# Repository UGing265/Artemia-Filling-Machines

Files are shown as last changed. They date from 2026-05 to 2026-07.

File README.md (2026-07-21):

# Máy Chiết Artemia

Máy chiết chiết tự động cho artemia (tôm muối) với kiểm soát thể tích chính xác và giám sát thời gian thực.

## Vấn Đề

Chiết chiết ống tube thủ công cho artemia tốn thời gian và không nhất quán. Mỗi ống cần liều lượng chính xác 5ml với xác nhận trực quan, và việc theo dõi số lượng ống trong quá trình xử lý là rất quan trọng để kiểm soát chất lượng.

## Giải Pháp

Hệ thống chiết tự động dựa trên Arduino:
- Chiết ống với thể tích tự động dựa trên cài đặt thời gian
- Đếm số ống đã chiết bằng cảm biến quang điện
- Hiển thị tốc độ, thời gian bơm và số lượng ống thời gian thực trên LCD
- Điều chỉnh tốc độ bơm và thời gian chiết trực tiếp bằng 2 biến trở độc lập
- Hỗ trợ hủy quá trình khẩn cấp (Abort) bằng nút bấm cứng

## Linh Kiện

| Linh Kiện | Công Dụng |
|---|---|
| Arduino CNC Shield V3.00 | Board điều khiển chính |
| L298N DC Motor Driver | Điều khiển tốc độ/chiều motor bơm |
| Nema 17 Stepper Motor | Truyền động cơ cấu xoay |
| LCD 16x4 I2C (PCF8574) | Hiển thị trạng thái và thông số |
| Cảm Biến Quang (E3F-DS30C4) | Phát hiện vị trí ống để đếm và kích hoạt bơm |
| Công Tắc Hành Trình (JL012-13) | Nút hủy quá trình (Abort) / Homing |
| 2 x Biến Trở 10K | Điều chỉnh tốc độ bơm và thời gian bơm |
| Bơm Peristaltic 5V | Chiết dung dịch artemia |

## Máy Trạng Thái

```text
ROTATING (Xoay mâm) → SENSOR_CHECK (Kiểm tra ống)
      ├─ [Có ống] → PUMP_WAIT (Đợi ổn định 1s) → PUMP_FILL (Bơm dung dịch) → PUMP_DONE (Đợi 3s) → ROTATING
      └─ [Không ống] → NO_TUBE_WAIT (Đợi 5s) → ROTATING

* Nút Abort: Hủy quá trình đang chạy bất kỳ lúc nào và đưa hệ thống về trạng thái ban đầu.
* Bơm sẽ tự dừng nếu mất ống (rớt ống) trong quá trình bơm.
```

## Điều Chỉnh Bơm Trực Tiếp

Hệ thống cho phép điều chỉnh trực tiếp các thông số bơm thông qua 2 núm vặn:
1. **Biến trở tốc độ (Chân A1):** Điều chỉnh tốc độ quay của động cơ bơm (PWM: 0 - 255).
2. **Biến trở thời gian (Chân A2):** Điều chỉnh thời gian bơm cho mỗi ống (từ 2.0 giây đến 20.0 giây).
Mọi thay đổi đều được cập nhật thời gian thực trên màn hình LCD.

## Demo

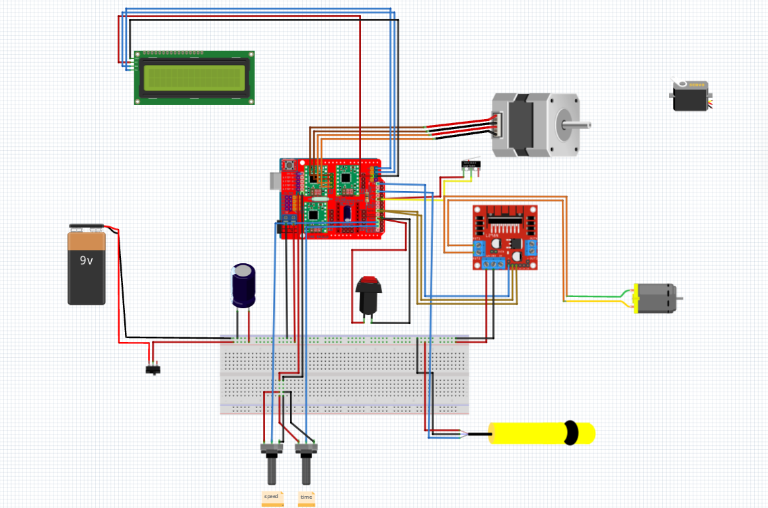
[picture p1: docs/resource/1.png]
Demo Máy Chiết


Video Demo (https://youtu.be/GX13D0-sERE)

## Nhóm

- **kiến trúc sư**: ZT
- **kĩ sư**: DevShiroru

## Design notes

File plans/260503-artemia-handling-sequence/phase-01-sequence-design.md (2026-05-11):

# Phase 1: Artemia Handling Sequence Design

## Context Links
- Main code: `ArtemiaCode/ArtemiaCode.ino`
- Plan: `plans/260503-artemia-handling-sequence/plan.md`

## Overview
- Priority: P1 (High)
- Status: Completed
- Brief description: Design sensor-triggered pump sequence replacing current hardcoded rotation+pump cycle

## Current Behavior (loop())

Current code in `loop()`:
1. Run stepper 1 revolution (stepsPerRev steps)
2. delay(1000) - rest 1 second
3. runPumpCycle() - pump 2 seconds OR until 5ml
4. displayUpdate()

This is HARDCODED - no sensor awareness.

## Required Behavior

```
loop()
├── Check abort button (existing)
├── Handle calibration states (existing)
└── IDLE state → NEW SEQUENCE:

    Step A: Rotate 1 revolution
    │
    Step B: Check sensor immediately after rotation
    │       └── If sensor HIGH (tube detected):
    │               ├── Wait 3s
    │               ├── Pump ON → auto-stop at 5ml (timeout 5s)
    │               ├── Pump OFF
    │               ├── tubeCount++
    │               ├── Wait 5s
    │               └── → back to Step A
    │       └── If sensor LOW (no tube):
    │               ├── Wait 10s (user places tube)
    │               └── → back to Step A
    │
```

## Key Design Decisions

### 1. Sensor Detection Timing
- Sensor is checked AFTER rotation completes
- If tube detected → 3s delay → pump (5ml over ~5s)
- If no tube → 10s wait → next rotation (giving user time to place tube)

### 2. 3s Delay Before Pumping
- Purpose: Let tube settle into position
- Prevents premature pumping

### 3. Pump Auto-Stop
- Stop at TARGET_VOLUME (5ml) with ~5s timeout
- Use flowRateCalibrated for volume estimation

### 4. Post-Pump Sequence
- Increment tubeCount
- Wait 5s (tube settling)
- Continue to next rotation

### 5. No-Tube Timeout
- After full rotation with no tube detected
- Wait 10s (polling sensor during this time)
- If tube placed within 10s → trigger pump sequence
- If timeout → continue rotation anyway

## Sequence State Machine

```cpp
enum HandleState {
  ROTATING,        // Stepper rotating 1 revolution
  SENSOR_CHECK,   // After rotation, check sensor
  PUMP_WAIT,      // Waiting 1s before pump
  PUMPING,        // Pump running, auto-stop
  PUMP_DONE,      // Pump stopped, wait 2s
  NO_TUBE_WAIT    // No tube detected, wait 10s
};
```

## Edge Cases

| Case | Handling |
|---|---|
| Tube removed during pumping | Continue until 5ml |
| Sensor flickers | Debounce 50ms (existing DEBOUNCE_SENSOR) |
| Button pressed during sequence | abortAll() immediately |
| Power loss during pump | pumpRunning flag reset on startup |

## LCD Display Updates

During sequence:
```
Line 0: "MAY CHIET ARTERMIA"
Line 1: "Speed:XXX"
Line 2: "Tubes:X |....|"
Line 3: "Time:Xs"
```

Where:
- Speed: current pump PWM (0-255)
- Tubes: count of filled tubes
- Time: processing time (adjustable 2s-20s via potentiometer)
- Bar: filled `|` = tube detected, empty `-` = no tube

Where YYY = ROTATE | WAIT1S | PUMPING | WAIT2S | NO_TUBE | DONE

## Related Code Changes

Files to modify: `ArtemiaCode/ArtemiaCode.ino`
- Add `HandleState` enum
- Add state variable `HandleState handleState = ROTATING`
- Add state timer `unsigned long stateStartTime = 0`
- Add processing time variable `int processingTimeS = 5` (default, adjustable 2-20s)
- Replace IDLE loop content with state machine
- Rewrite `displayUpdate()` to new LCD layout (MAY CHIET ARTERMIA title)
- Add sensor status to LCD (HI/LO)
- Potentiometer A1 adjusts processing time (2s-20s mapped from 0-1023)

## Implementation Steps

1. Add `HandleState` enum after existing enums
2. Add state variables: `handleState`, `stateStartTime`
3. Rewrite IDLE loop section as state machine
4. Add `checkOverflow()` helper in pump cycle
5. Add LCD state display in `displayUpdate()`
6. Test sequence with physical hardware

## Todo List
- [ ] Add HandleState enum
- [ ] Add state variables
- [ ] Implement state machine in loop()
- [ ] Update displayUpdate() with state info
- [ ] Compile and verify

## Success Criteria
- [ ] Sensor HIGH → 3s delay → pump fills 5ml → stops
- [ ] After pump: tubeCount++, wait 5s, rotate
- [ ] No tube after rotation → wait 10s, rotate (no pump)
- [ ] Processing time adjustable via pot (2s-20s)
- [ ] LCD shows: MAY CHIET ARTERMIA, Speed, Tubes, Time, Sensor status
- [ ] Abort button works during any state

## Risk Assessment
- Risk: State machine complexity
- Mitigation: Keep states simple, each does one thing
- Risk: Timing sensitive (1s, 2s, 10s)
- Mitigation: Use millis() for accurate timing

## Security Considerations
- User can always abort via button
- Overflow protection prevents mess
- No network/internet access

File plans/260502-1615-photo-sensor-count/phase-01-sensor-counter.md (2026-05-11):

---
title: "Phase 1: Photoelectric Sensor + Tube Counter"
description: "Implement photoelectric sensor detection and tube counting with reset button"
status: completed
owner: claude
priority: P2
created: 2026-05-02
---

## Context Links

- Parent: [plan.md](../plan.md)
- Code: `ArtemiaCode/ArtemiaCode.ino`

## Overview

Add photoelectric sensor to count tubes and push button to reset counter.

### Pin Assignment

| Component | Pin | Mode |
|---|-----|---|
| Photoelectric sensor | D10 (Y+) | INPUT_PULLUP (NC = no object, LOW = object detected) |
| Reset button | A0 (Abort) | INPUT_PULLUP (NC = not pressed, LOW = pressed) |

### Debounce

- Sensor: 50ms debounce to avoid double-counting
- Button: 100ms debounce for mechanical switch

## Requirements

1. Photoelectric sensor on D7 - detect falling edge (HIGH→LOW transition means object detected)
2. Tube counter variable `tubeCount` starts at 0
3. Each detection: tubeCount++
4. Push button on D6 - when pressed, set tubeCount = 0
5. No LCD changes in this phase

## Implementation Steps

1. Define pin constants: `sensorPin = 7`, `resetBtnPin = 6`
2. Add `tubeCount` global variable (int)
3. Add `lastSensorTrigger = 0` for debounce timing
4. In setup(): `pinMode(sensorPin, INPUT_PULLUP)`, `pinMode(resetBtnPin, INPUT_PULLUP)`
5. In loop(): implement detection logic:
   - Read sensor: if LOW and (now - lastSensorTrigger) > 50ms → count++
   - Read button: if LOW → reset tubeCount to 0
   - Update lastSensorTrigger on count

## Code Snippet

```cpp
const int sensorPin = 10;   // Y+ on CNC shield (D10)
const int resetBtnPin = A0; // Abort signal (A0)

int tubeCount = 0;
unsigned long lastSensorTrigger = 0;
const int DEBOUNCE_SENSOR = 50;
const int DEBOUNCE_BUTTON = 100;

void setup() {
  pinMode(sensorPin, INPUT_PULLUP);
  pinMode(resetBtnPin, INPUT_PULLUP);
}

void loop() {
  // Sensor detection (NC = HIGH, detected = LOW)
  if (digitalRead(sensorPin) == LOW &&
      millis() - lastSensorTrigger > DEBOUNCE_SENSOR) {
    tubeCount++;
    lastSensorTrigger = millis();
  }

  // Reset button (NC = HIGH, pressed = LOW)
  if (digitalRead(resetBtnPin) == LOW) {
    tubeCount = 0;
    delay(DEBOUNCE_BUTTON);
  }
}
```

## Todo List

- [ ] Define pin constants
- [ ] Add tubeCount and debounce variables
- [ ] Configure pin modes in setup()
- [ ] Implement detection + count logic in loop()
- [ ] Implement reset button logic

## Success Criteria

- Sensor triggers count when object passes in front of it
- Button press resets counter to 0
- No double-counting from bounce
- Existing pump/lcd code unchanged

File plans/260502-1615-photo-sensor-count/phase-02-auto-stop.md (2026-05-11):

---
title: "Phase 2: 5ml Auto-Stop Pump + LCD Tube Count"
description: "Implement pump auto-stop at 5ml and LCD display for tube count"
status: completed
owner: claude
priority: P2
created: 2026-05-02
---

## Context Links

- Parent: [plan.md](../plan.md)
- Deps: [phase-01-sensor-counter.md](./phase-01-sensor-counter.md)
- Code: `ArtemiaCode/ArtemiaCode.ino`

## Overview

Add auto-stop pump when 5ml reached and show tube count on LCD row 3.

### Auto-Stop Logic

- Existing `pumpVolume` calculated from: `pumpRuntime / 1000.0 * FLOW_RATE`
- Add check: if `pumpVolume >= 5.0` → stop pump immediately
- In existing pump running code, add condition to turn off pumpPWM

### LCD Display (row 3)

- Show `Tubes: XX` on LCD row 3
- Clear remaining chars to avoid ghosting

## Implementation Steps

1. Add constant: `const float TARGET_VOLUME = 5.0;`
2. In pump running block:
   - After `analogWrite(pumpPWM, pumpSpeed)` add check
   - Before delay: calculate current volume
   - If volume >= 5.0: turn off pump, skip delay
3. In `displayUpdate()`:
   - Add row 3 display: `lcd.print("Tubes: ")` + tubeCount

## Code Snippet

```cpp
const float TARGET_VOLUME = 5.0;

// Inside pump running block:
analogWrite(pumpPWM, pumpSpeed);
delay(2000);

// Add auto-stop check inside the running block:
float currentVolume = (millis() - pumpStartTime) / 1000.0 * FLOW_RATE;
if (currentVolume >= TARGET_VOLUME) {
  analogWrite(pumpPWM, 0);  // Stop pump
  pumpRuntime += millis() - pumpStartTime;
  pumpVolume = pumpRuntime / 1000.0 * FLOW_RATE;
  pumpRunning = false;
  currentSpeed = 0;
  displayUpdate();
  return;  // Skip remaining delay
}

// In displayUpdate():
lcd.setCursor(0, 3);
lcd.print("Tubes:");
lcd.print(tubeCount);
lcd.print("    ");
```

## Todo List

- [ ] Add TARGET_VOLUME constant
- [ ] Add auto-stop check in pump logic
- [ ] Add Tubes: display on LCD row 3
- [ ] Verify compilation

## Success Criteria

- Pump stops automatically when volume >= 5ml
- LCD shows tube count on row 3
- Existing sensor/button logic still works
- No compilation errors

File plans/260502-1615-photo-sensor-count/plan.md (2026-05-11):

---
title: "Photoelectric Sensor Counting + 5ml Auto-Stop Pump"
description: "Add tube counting via photoelectric sensor with reset button, and auto-stop pump at 5ml with LCD display"
status: completed
priority: P2
effort: 2h
branch: main
tags: [arduino, photoelectric-sensor, pump-control, lcd]
created: 2026-05-02
---

# Photoelectric Sensor Counting + 5ml Auto-Stop Pump Plan

## Requirements

1. **Photoelectric sensor** - count +1 each time a tube passes detected
2. **Push button** - reset tube counter to 0 when pressed
3. **5ml auto-stop pump** - stop pump automatically when pumpVolume >= 5ml
4. **LCD display** - show tube count + pump volume (4th row)

## Architecture

- Photoelectric sensor: digital input pin (use interrupt for edge detection)
- Reset button: digital input pin with pull-down resistor (or internal pullup)
- Pump control: existing pumpDir + pumpPWM pins
- Volume tracking: existing pumpVolume variable (calculated from runtime × FLOW_RATE)
- LCD: existing 16x4 I2C display (rows 0-3)

## Display Format (16x4)

| Line | Content |
|---|---|
| 0 | Speed: XXX |
| 1 | Motor: XXXX |
| 2 | PumpVol: X.XX ml |
| 3 | Tubes: XX |

## Phases

| # | Phase | Status | Effort | Link |
|---|---|---|---|---|
| 1 | Photoelectric sensor + tube counter | pending | 1h | [phase-01](./phase-01-sensor-counter.md) |
| 2 | 5ml auto-stop pump + LCD tube count | pending | 1h | [phase-02](./phase-02-auto-stop.md) |

## Dependencies

- Existing: LCD 16x4 I2C, pump L298N, potentiometer
- New: Photoelectric sensor (D10/Y+), push button (A0/Abort)
- Library: none (arduino built-in)

## Risk Assessment

- Sensor bounce: use proper debouncing (software delay or hardware RC)
- Flow rate calibration: FLOW_RATE constant may need tuning for accuracy
- 5ml precision: depends on pump consistency and calibration

## Unresolved Questions

- What pin for photoelectric sensor? Will assign default (D7)
- What pin for reset button? Will assign default (D6)
- Debounce delay: 50ms typical for mechanical button

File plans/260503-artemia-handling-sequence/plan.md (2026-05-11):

---
title: "Artemia Handling Sequence with Sensor-Triggered Pump"
description: "Photoelectric sensor detects tube → wait 3s → pump 5ml in ~5s → wait 5s → rotate. Processing time adjustable 2-20s via pot."
status: completed
priority: P1
effort: 2h
branch: main
tags: [feature, motor-control, arduino, pump-control]
created: 2026-05-03
---

# Artemia Handling Sequence with Sensor-Triggered Pump

## Overview

Replace the current hardcoded rotation+pump cycle with a sensor-driven sequence:
- Photoelectric sensor detects tube → wait 3s → pump fills 5ml (~5s) → wait 5s → rotate
- If no tube detected after rotation, wait 10s then continue searching

## LCD Display

```
Line 0: "MAY CHIET ARTERMIA"
Line 1: "Speed:XXX"
Line 2: "Tubes:X |....|"
Line 3: "Time:Xs"
```
- Speed: pump PWM (0-255)
- Tubes: filled tube count
- Time: adjustable processing time (2s-20s via pot)
- Bar: `|` = tube detected, `-` = no tube

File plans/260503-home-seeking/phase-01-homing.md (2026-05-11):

# Phase 1: Homing Implementation

## Context Links
- Main code: `ArtemiaCode/ArtemiaCode.ino`
- Plan: `plans/260503-home-seeking/plan.md`

## Overview
- Priority: P1 (High)
- Status: Pending
- Brief description: Implement slow 360° homing rotation on startup with Z-limit switch detection

## Hardware Pinout
CNC Shield V3 pin mapping:
| Signal | Arduino Pin | CNC Shield V3 |
|---|---|---|
| Step (Z) | D4 | Z+ |
| Dir (Z) | D7 | Z- |
| Limit Switch (Z) | D9 | Z-Limit |

## Key Insights
- Current stepper uses stepPin=2, dirPin=5 for "X" axis
- CNC Shield V3: Z-axis step/dir on D4/D7 (not D2/D5 as in code - code may be non-standard)
- Z-limit switch on D9 (Arduino pin 9 on CNC Shield)
- User confirmed limit switch is on Z pin

## Requirements

### Functional Requirements
1. On `setup()` after LCD init, run homing sequence
2. Rotate motor SLOWLY (wider pulse width) for 2 full rotations max
3. Check Z-limit switch (D9) every step - if pressed, stop immediately
4. If home found: wait 10 seconds, LCD shows "ACTIVE", then proceed to normal loop
5. If home NOT found after 2 rotations: LCD shows "TURN OFF-ON" error, loop forever (no pump)

### Non-Functional Requirements
- Homing speed: slower than normal (safer for homing)
- Timeout: exactly 2 full rotations (~8 seconds at slow speed)
- No pump activity during homing

## Architecture

```
setup()
  └─ lcdInit()
  └─ homeSeekingSequence()    // NEW
       ├─ Set direction (toward home - user may specify)
       ├─ For 2 rotations:
       │   └─ For each step:
       │       ├─ digitalWrite(stepPin, HIGH)
       │       ├─ delayMicroseconds(3000)
       │       ├─ digitalWrite(stepPin, LOW)
       │       ├─ delayMicroseconds(500)
       │       └─ Check limit switch (D9) → if pressed, BREAK
       └─ If switch found:
           ├─ Stop motor
           ├─ LCD: "HOMING DONE"
           ├─ Wait 10s
           ├─ LCD: "ACTIVE"
           └─ Return (proceed to loop)
       └─ If timeout:
           ├─ LCD: "TURN OFF-ON"
           └─ while(1) {}  // Infinite loop - user must reset
```

## Related Code Files
- `ArtemiaCode/ArtemiaCode.ino`: Modify `setup()` to add homing sequence

## Implementation Steps

1. **Add Z-limit switch pin definition** (after existing pin definitions):
   ```cpp
   const int limitSwitchZ = 9;  // Z-limit on CNC Shield V3 (D9)
   ```

2. **Configure pin mode in `setup()`**:
   ```cpp
   pinMode(limitSwitchZ, INPUT_PULLUP);
   ```

3. **Add `homeSeekingSequence()` function before `setup()`**:
   - Use slower step speed: `delayMicroseconds(3000)` high, `delayMicroseconds(500)` low
   - Loop for 2 × `stepsPerRev` iterations
   - Check `digitalRead(limitSwitchZ) == LOW` at each step
   - If switch found: stop, display "HOMING DONE", wait 10s, display "ACTIVE", return
   - If timeout: display "TURN OFF-ON", infinite loop

4. **Call `homeSeekingSequence()` in `setup()`** after LCD init, before pump/button config

## Todo List
- [ ] Add limit switch pin definition
- [ ] Configure pin mode INPUT_PULLUP
- [ ] Implement homeSeekingSequence() function
- [ ] Call homing in setup() after LCD init
- [ ] Verify compilation

## Success Criteria
- [ ] Motor rotates slowly on startup
- [ ] If limit switch pressed within 2 rotations: motor stops, 10s wait, LCD shows "ACTIVE", pump runs
- [ ] If limit switch NOT pressed within 2 rotations: LCD shows "TURN OFF-ON", system halts
- [ ] Code compiles without errors

## Risk Assessment
- **Risk**: Motor spins continuously if switch wiring is wrong
- **Mitigation**: 2-rotation timeout prevents indefinite spinning
- **Risk**: Switch is NC (normally closed) vs NO (normally open)
- **Mitigation**: Test with `INPUT_PULLUP` and check logic - if NC, detect HIGH instead of LOW

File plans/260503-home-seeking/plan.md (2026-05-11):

---
title: "NEMA Homing Sequence with Limit Switch"
description: "Add home-seeking behavior on startup: slow 360° rotation, detect Z-limit switch, 10s wait + LCD activation, or timeout error message"
status: pending
priority: P1
effort: 2h
branch: main
tags: [feature, motor-control, arduino]
created: 2026-05-03
---

# NEMA Homing Sequence with Limit Switch

## Overview

Implement home-seeking behavior on system startup:
- NEMA motor rotates 360° slowly to find home position
- Limit switch connected to Z pin on CNC Shield V3
- If switch pressed → motor stops, wait 10s, LCD shows "ACTIVE", pump activates
- If home not found after 2 full rotations → LCD shows error message to power cycle

## Phases

| # | Phase | Status | Effort | Link |
|---|---|---|---|---|
| 1 | Homing Implementation | Pending | 1h | [phase-01](./phase-01-homing.md) |
| 2 | Testing | Pending | 1h | - |

## Dependencies

- Requires `ArtemiaCode.ino` modification
- Uses existing LCD, stepper, and limit switch infrastructure

## Hardware Pinout

| Component | Pin | CNC Shield V3 |
|---|-----|---|
| NEMA Stepper (Step) | D4 | Z+ |
| NEMA Stepper (Dir) | D7 | Z- |
| Limit Switch (Z) | D9 | Z-Limit |

## Timing

- Slow rotation speed: ~3000µs pulse width (slower than current 3000+100)
- 2 rotations timeout = ~8 seconds at slow speed
- Home found → 10s wait → LCD "ACTIVE" → proceed to normal operation

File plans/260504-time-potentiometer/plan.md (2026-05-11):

# Plan: Time Potentiometer on A2

## Overview
Add a potentiometer on **A2** of CNC Shield V3 to control pump processing time from **2s to 20s**. Time is captured when pumping starts — **locked until pumping completes**.

## Changes (1 file)

### ArtemiaCode/ArtemiaCode.ino

**1. Add pin constant** (after line 66):
```cpp
const int timePot = A2;  // Potentiometer for pump process time (2-20s)
```

**2. Add `readPotTime()` function** (after line 220):
```cpp
int readPotTime() {
  int potValue = analogRead(timePot);
  return map(potValue, 0, 1023, 2, 20);  // 2s to 20s
}
```

**3. Add captured time variable** (near pump state variables, around line 45):
```cpp
int capturedProcessTime = 0;  // Locked time when pumping starts
```

**4. Update PUMP_FILL logic** — capture time when pump starts, use captured value:
```cpp
// When entering PUMP_FILL (around line 313-314):
capturedProcessTime = readPotTime();  // Lock in the time

// When checking timeout (line 356):
} else if (millis() - stateStartTime >= capturedProcessTime * 1000UL) {
```

**5. Update displayUpdate()** (line 592):
```cpp
// OLD:
int potValue = analogRead(speedPot);

// NEW:
int potValue = analogRead(timePot);
```

**6. Update docs/operation-rules.md** pin mapping:
- A1: Speed potentiometer (pump speed 0-255)
- A2: Time potentiometer (processing time 2-20s) ← NEW

## Behavior Rule
- **Time is locked once pumping starts** — even if user turns the pot mid-pump, the current pump cycle keeps its original time
- Time is re-read from pot at the start of each new PUMP_FILL cycle

## Dependencies
- None — single file, straightforward addition

## Validation
- [ ] A2 pin defined for time potentiometer
- [ ] `readPotTime()` returns 2-20s range
- [ ] LCD line 3 reads from A2 (timePot)
- [ ] Pump timeout uses captured/process time, not live pot value

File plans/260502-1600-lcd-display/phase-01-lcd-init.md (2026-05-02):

---
title: "LCD Initialization Phase"
description: "Add LiquidCrystal_I2C library and initialize LCD in setup()"
status: completed
priority: P2
effort: 30m
branch: main
tags: [arduino, lcd]
created: 2026-05-02
---

# Phase 01: LCD Initialization

## Context Links

- Original code: `ArtemiaCode/ArtemiaCode.ino`
- Library: LiquidCrystal_I2C

## Overview

- Priority: P2
- Status: Pending
- Add LCD I2C library initialization in setup()

## Key Insights

- PCF8574 I2C backpack on LCD 16x4
- Address 0x27 is standard for most backpack modules
- Library: https://github.com/johnrickman/LiquidCrystal_I2C

## Requirements

- Include LiquidCrystal_I2C.h header
- Create LiquidCrystal_I2C object: `LiquidCrystal_I2C lcd(0x27, 16, 4)`
- Init LCD in setup(): `lcd.init()`, `lcd.backlight()`

## Related Code Files

- Modify: `ArtemiaCode/ArtemiaCode.ino`

## Implementation Steps

1. Add `#include <Wire.h>` and `#include <LiquidCrystal_I2C.h>` at top of file
2. Create global LCD object: `LiquidCrystal_I2C lcd(0x27, 16, 4);`
3. In setup(), add `lcd.init();` and `lcd.backlight();`
4. Clear screen test: `lcd.setCursor(0,0); lcd.print("LCD OK");`

## Todo List

- [ ] Add Wire.h include
- [ ] Add LiquidCrystal_I2C.h include
- [ ] Create LCD object
- [ ] Init LCD in setup()

## Success Criteria

- Code compiles without errors
- LCD displays "LCD OK" on first line

## Risk Assessment

- I2C address might differ (0x27 is default but could be 0x3F)
- Library conflict with other Wire devices

## Security Considerations

- None (local Arduino, no network)

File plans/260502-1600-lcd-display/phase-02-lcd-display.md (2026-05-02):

---
title: "LCD Display Logic Phase"
description: "Add tracking variables and display update logic for speed, motor rotation, pump volume"
status: completed
priority: P2
effort: 1h
branch: main
tags: [arduino, lcd]
created: 2026-05-02
---

# Phase 02: LCD Display Logic

## Context Links

- Phase 01: `./phase-01-lcd-init.md`
- Original code: `ArtemiaCode/ArtemiaCode.ino`

## Overview

- Priority: P2
- Status: Pending
- Add tracking variables and display update logic

## Key Insights

- Motor rotation counted via step pulses (each step = 1.8° for 200-step motor, or 0.9° for 400-step)
- Pump volume estimated: runtime_seconds × flow_rate_constant (ml/s)
- Update LCD every loop iteration, but throttle updates to avoid flicker

## Requirements

### Variables to Add

```cpp
// Tracking variables
unsigned long motorSteps = 0;      // Total step pulses
unsigned long pumpRuntime = 0;    // Pump running time in ms
float pumpVolume = 0.0;           // Estimated volume in ml
int currentSpeed = 0;              // Current PWM value
bool pumpRunning = false;          // Pump state flag
unsigned long pumpStartTime = 0;  // For runtime tracking
```

### Display Format (16x4)

| Line | Content | Example |
|---|---|---|
| 1 | Speed: XXX | Speed: 255 |
| 2 | Motor: XXXX | Motor: 1234 |
| 3 | PumpVol: XXXX ml | PumpVol: 45.2 ml |
| 4 | (spare) | |

### Display Update Logic

- Update LCD every ~500ms (not every loop)
- Use `millis()` for non-blocking timing
- Print values with `lcd.print()`

## Related Code Files

- Modify: `ArtemiaCode/ArtemiaCode.ino`

## Implementation Steps

1. Add tracking variables after pump pin definitions
2. In loop(), after `analogWrite(pumpPWM, 255)`:
   - Set pumpRunning = true, pumpStartTime = millis()
3. After `analogWrite(pumpPWM, 0)`:
   - pumpRuntime += millis() - pumpStartTime
   - pumpVolume = pumpRuntime / 1000.0 * FLOW_RATE (ml/s)
   - pumpRunning = false
4. After step pulse in loop():
   - motorSteps++
5. Add displayUpdate() function called every 500ms
6. displayUpdate() shows Speed, Motor count, PumpVol on LCD

## Todo List

- [ ] Add tracking variables
- [ ] Track pump runtime
- [ ] Track motor steps
- [ ] Calculate pump volume
- [ ] Add displayUpdate() function
- [ ] Call displayUpdate() in loop

## Success Criteria

- LCD shows Speed, Motor count, PumpVol updated in real-time
- Values update correctly when motor/pump run

## Risk Assessment

- Division by zero in volume calc (guard with if pumpRuntime > 0)
- Integer overflow for long runtime (use unsigned long)

## Security Considerations

- None

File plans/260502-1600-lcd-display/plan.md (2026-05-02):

---
title: "Add LCD 16x4 I2C Display to Arduino Code"
description: "Add LCD 16x4 I2C (PCF8574) display showing pump speed, motor rotation count, and pump volume"
status: completed
priority: P2
effort: 2h
branch: main
tags: [arduino, lcd, embedded]
created: 2026-05-02
---

# LCD Display Implementation Plan

## Overview

Add LCD 16x4 I2C display to show pump speed (PWM 0-255), motor rotation count, and estimated pump output volume. Track stepper steps for rotation counting, track pump runtime for volume estimation.

## Display Format (16x4)

| Line | Content |
|---|---|
| 1 | Speed: XXX |
| 2 | Motor: XXXX |
| 3 | PumpVol: XXXX |
| 4 | (reserved/spare) |

## Components

- LCD: I2C PCF8574 backpack, address 0x27, 16 cols x 4 rows
- Library: LiquidCrystal_I2C
- Variables: motorSteps (step counter), pumpVolume (estimated ml), currentSpeed

## Phases

| # | Phase | Status | Effort | Link |
|---|---|---|---|---|
| 1 | Add LCD library + init | Pending | 30m | [phase-01](./phase-01-lcd-init.md) |
| 2 | Add LCD display logic | Pending | 1h | [phase-02](./phase-02-lcd-display.md) |
| 3 | Verify compile | Pending | 30m | [phase-03](./phase-03-verify.md) |

## Dependencies

- Original stepper+pump code unchanged
- LiquidCrystal_I2C library required

## Notes

- LCD 16x4 has 4 rows (vs typical 16x2 which has 2 rows)
- Pump volume estimated from runtime × flow rate constant

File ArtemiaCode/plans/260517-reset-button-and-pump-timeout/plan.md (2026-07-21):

---
title: Fix Reset Button and PUMP_WAIT Stuck Issue
description: Two bugs in ArtemiaCode.ino: reset button not working and PUMP_WAIT stuck when tube removed
status: completed
priority: high
effort: 2h
branch: main
tags: [bugfix, reset-button, pump-wait, artemia]
created: 2026-05-17
completed: 2026-05-17
---

# Plan: Fix Reset Button and PUMP_WAIT Stuck Issue

## Summary

Two bugs in ArtemiaCode.ino:
1. **Reset button doesn't work** - button checked only in unused `runPumpCycle()`, not in main handle sequence
2. **PUMP_WAIT stuck when tube removed** - timer resets in loop causing infinite 0.x second waiting

## Implementation Summary

Both issues were fixed in `ArtemiaCode.ino`:

1. **Reset button**: Added button monitoring at the start of `loop()` before the handle sequence. The code checks `digitalRead(resetBtnPin)`, debounces, and calls `abortAll()` when pressed.

2. **PUMP_WAIT stuck**: Changed the sensor check (lines 230-231) to transition to `ROTATING` state immediately when the tube disappears during `PUMP_WAIT`, instead of resetting the timer endlessly.

---

## Issue 1: Reset Button Not Working

### Root Cause

Button check exists only in `runPumpCycle()` (never called). Main loop has zero button monitoring.

### Fix

Add button monitoring at start of `loop()` before line 190:
```cpp
// Check reset button (external pull-up circuit)
bool btnState = digitalRead(resetBtnPin);
if (btnState == LOW && lastAbortBtnState == HIGH) {
  delay(DEBOUNCE_BUTTON);
  if (digitalRead(resetBtnPin) == LOW) {
    abortAll();
    return;
  }
}
if (btnState == HIGH && lastAbortBtnState == LOW) {
  lastAbortBtnState = HIGH;
}
```

---

## Issue 2: PUMP_WAIT Stuck When Tube Removed

### Root Cause

PUMP_WAIT lines 230-231:
```cpp
if (digitalRead(sensorPin) == LOW) {
  stateStartTime = millis();  // Reset timer - wait for stable tube
}
```

When tube removed, sensor goes LOW → timer resets. If sensor bounces, timer resets infinitely at 0.x seconds → never reaches 3s → stuck forever.

**User behavior:** During 1s PUMP_WAIT delay, user removes tube → sensor goes LOW → code resets timer → user keeps tube out → sensor stays LOW → timer resets again and again → stuck.

### Fix

Change lines 230-231. If tube disappears during PUMP_WAIT, go to ROTATING immediately instead of resetting timer:

```cpp
// OLD (lines 230-231):
if (digitalRead(sensorPin) == LOW) {
  stateStartTime = millis();  // Reset timer - wait for stable tube
}

// NEW:
if (digitalRead(sensorPin) == LOW) {
  // Tube disappeared during PUMP_WAIT - give up and rotate back
  handleState = ROTATING;
  stateStartTime = millis();
  break;
}
```

---

## Files to Modify

| File | Change |
|---|---|
| `ArtemiaCode.ino` | Add button check at start of `loop()` (before line 190) |
| `ArtemiaCode.ino` | Change PUMP_WAIT sensor check to abort instead of timer reset (lines 230-231) |

---

## Success Criteria

1. **Reset button works** - pressing A0 resets tubeCount to 0 from any state
2. **PUMP_WAIT abort** - if tube removed during PUMP_WAIT, machine goes back to ROTATING within 1 loop cycle (no stuck timer)
3. **Normal flow intact** - if tube stays present, PUMP_WAIT completes normally after 3s

---

## Implementation Order

1. Add button monitoring in `loop()` — enables reset testing
2. Fix PUMP_WAIT sensor check — prevents stuck behavior
3. Compile check

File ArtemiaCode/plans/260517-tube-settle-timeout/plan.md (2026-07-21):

---
title: Extend PUMP_WAIT Timeout to 9s
description: Extend the tube stability timeout during PUMP_WAIT from 6s to 9s, giving the tube more time to settle during the 1s delay period before pump activates.
status: completed
priority: medium
effort: low
branch: main
tags: [timeout, pump, bug-fix]
created: 2026-05-17
updated: 2026-05-17
---

# Plan: Extend PUMP_WAIT Timeout to 9s

## Summary

Changed timeout from 6s to 9s (waitElapsed >= 9000).

## Files to Modify

| File | Change |
|---|---|
| `ArtemiaCode.ino` | Line 267: change `waitElapsed >= 6000` to `waitElapsed >= 9000` |

## Current Behavior (Bug)

Line 267:
```cpp
} else if (waitElapsed >= 6000) {
```

- PUMP_WAIT has 1s delay (`PUMP_WAIT_DELAY = 1000`)
- 6s timeout gives only 5 extra seconds after the 1s wait = tube must stabilize within 5s after initial detection
- If user drops tube and it takes >5s to settle, machine aborts and rotates back

## Fix

Change timeout from 6s to 9s:
```cpp
} else if (waitElapsed >= 9000) {
```

- 9s timeout = 8 extra seconds after the 1s wait = tube has 8s to settle
- More forgiving for slower tube placement

## Implementation Steps

1. Edit `ArtemiaCode.ino` line 267: `waitElapsed >= 6000` → `waitElapsed >= 9000`
2. Update comment to reflect new timeout

## Success Criteria

1. Machine waits 1s then starts pump if tube stays in position
2. Machine aborts to ROTATING only after tube has 8s (not 5s) to stabilize
3. No other behavior changes

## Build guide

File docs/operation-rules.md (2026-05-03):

# Artemia Filling Machine - Complete Operation Rules

## Hardware Configuration

### Pin Mapping
| Pin | Function |
|-----|---|
| D2 | Stepper step pulse (X axis) |
| D5 | Stepper direction (X axis) |
| D9 | Limit switch X+ (homing) |
| D10 | Photoelectric sensor (Y+ input) |
| A1 | Speed potentiometer (pump speed 0-255) |
| A2 | Time potentiometer (pump process time 2-20s) |
| D11 | Pump PWM (L298N ENA → Z+) |

### Motor Settings
- Stepper: 100 steps/revolution (half-step mode, 400 steps/rotation, 2 rotations = homing)
- Pump: L298N driver, IN2 grounded
- Target fill volume: **5.0 ml**

---

## Startup Sequence

1. LCD shows `LCD OK Rate: X.XXX` for 1.5s
2. Homing sequence runs:
   - Rotates up to 2 full rotations toward limit switch
   - If limit switch triggered → `HOMING DONE!` → 10s countdown → start
   - If limit switch **NOT** triggered → `PLEASE TURN OFF SYSTEM !!!` (machine stops)
3. Machine enters IDLE state

---

## Main Handle Sequence (IDLE State)

```
ROTATING → SENSOR_CHECK → [tube?] → PUMP_WAIT (3s) → PUMP_FILL → PUMP_DONE (5s) → ROTATING
                                          ↓
                         [no tube] → NO_TUBE_WAIT (10s, poll) → ROTATING
```

### Step 1: ROTATING
- Stepper rotates **1 full revolution** (100 step pulses)
- Direction: HIGH (forward)
- Pulse: 3000µs on, 100µs off
- After completion → SENSOR_CHECK

### Step 2: SENSOR_CHECK
- Read photoelectric sensor (D10)
- If **HIGH** (tube detected) → PUMP_WAIT
- If **LOW** (no tube) → NO_TUBE_WAIT
- No timeout — immediate transition

### Step 3: PUMP_WAIT (3s confirmation)
- Wait up to **3 seconds** for tube to settle
- **Safety: If tube disappears during wait** → reset timer, keep waiting for stable tube
- Only after tube stays present for full 3s → PUMP_FILL
- If tube appears briefly then disappears → timer resets, must be stable for full 3s

### Step 4: PUMP_FILL
- Start pump at potentiometer-set speed (0-255 PWM)
- Auto-stop when volume reaches **5.0 ml**
- **Process time: 2-20 seconds** (set by A2 time potentiometer, captured when pumping starts)
- **Time is locked once pumping starts** — even if pot is turned mid-pump, current cycle keeps its original time
- **Safety: If tube disappears during pumping** → stop pump immediately, do NOT count, show `TUBE LOST! SKIP`, return to ROTATING
- On success → increment tubeCount → PUMP_DONE

### Step 5: PUMP_DONE
- Wait **5 seconds** post-fill
- Then return to ROTATING

### Step 6: NO_TUBE_WAIT (10s skip)
- Wait up to **10 seconds** for tube to be placed
- **If tube placed during wait** → go to PUMP_WAIT immediately
- After 10s timeout → return to ROTATING (skip)

---

## Safety Rules Summary

| Event | Action |
|---|---|
| Tube disappears during 3s wait | Reset timer, keep waiting (must be stable 3s to pump) |
| Tube disappears during pumping | Stop pump, no count, show `TUBE LOST! SKIP`, return to ROTATING |
| Abort button short press | Stop everything, reset tubeCount to 0, return to IDLE |

---

## Calibration Mode

**Enter:** Long press reset button (3+ seconds) while in IDLE

**Phase 1 - CALIBRATING (5s):**
- Pump runs at full speed (PWM 255)
- LCD shows `Time: Xs`
- User collects output
- Can abort: short press → `CALIB CANCELLED`

**Phase 2 - CALIB_INPUT:**
- LCD shows `ENTER ML: X.X` (potentiometer sets 0.0-5.0 ml)
- LCD shows `RATE: X.XXX ml/s` (calculated from volume / 5s)
- LCD shows `SHORT=SAVE LONG=CNL`

**Save:** Short press button → saves flowRate to EEPROM → `CALIB SAVED!`

**Cancel:** Long press button (3+ seconds) → `CALIB CANCELLED`

**EEPROM:** Stored at address 0, magic char 'A', float value

---

## Abort / Reset

**Trigger:** Short press reset button (any state except during calibration input)

**Actions:**
1. Stop pump immediately (PWM 0, dir LOW)
2. Reset pumpRuntime, pumpVolume, pumpRunning, currentSpeed to 0
3. Reset tubeCount to 0
4. Set systemState = IDLE
5. Set handleState = ROTATING
6. Show `!! ABORTED !!` on LCD for 1 second

---

## LCD Display (16x4 I2C)

| Line | Content | Description |
|---|---|---|
| 0 | `MAY CHIET ARTERMIA` | Machine name |
| 1 | `Speed:XXX` | Configured pump speed from A1 pot (0-255), not actual running speed |
| 2 | `Tubes:X ||||||` or `Tubes:X ------` | Tube count + sensor bar (| = tube present, - = empty) |
| 3 | `Time:Xs` | Processing time from A2 pot (2-20s map) |

---

## State Machine Reference

```
SystemState: IDLE | PUMPING | CALIBRATING | CALIB_INPUT

HandleState: ROTATING | SENSOR_CHECK | PUMP_WAIT | PUMP_FILL | PUMP_DONE | NO_TUBE_WAIT
```

**During CALIBRATING or CALIB_INPUT:** handleStateMachine() runs instead of main loop handle sequence

**Note:** PUMPING state exists in enum but main pumping logic is handled inside HandleState PUMP_FILL. runPumpCycle() is a separate function (unused in normal loop flow).

---

## Constants Reference

| Constant | Value | Usage |
|---|---|---|
| PUMP_WAIT_DELAY | 3000ms | 3s tube confirmation |
| POST_PUMP_DELAY | 5000ms | 5s after pump stops |
| NO_TUBE_DELAY | 10000ms | 10s skip wait |
| PUMP_TIMEOUT | 5000ms | Max pump runtime (fallback) |
| CALIB_DURATION | 5000ms | 5s calibration pump |
| CALIB_LONG_PRESS | 3000ms | Long press threshold |
| TARGET_VOLUME | 5.0 ml | Auto-stop volume |
| PROCESS_TIME_MIN | 2 s | Min pump process time |
| PROCESS_TIME_MAX | 20 s | Max pump process time |
| EEPROM_DEFAULT_RATE | 0.5 ml/s | Fallback flow rate |
| DEBOUNCE_SENSOR | 50ms | Sensor debounce |
| DEBOUNCE_BUTTON | 100ms | Button debounce |
| stepsPerRev | 100 | Stepper steps per revolution |

---

## Edge Cases

- **Potentiometer at 0:** Pump speed = 0, pump never fills, will timeout after set time
- **First boot (no EEPROM):** Uses default flow rate 0.5 ml/s
- **Calibration input = 0:** Rate shows `---`, short press does not save
- **Calibration cancelled:** Returns to IDLE without saving
- **Homing fails:** Machine halts with `PLEASE TURN OFF SYSTEM !!!`
- **Tube removed mid-fill:** Tube is NOT counted, machine skips to next rotation
- **Tube removed during 3s wait:** Timer resets, must stay stable for full 3s

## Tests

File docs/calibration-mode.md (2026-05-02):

# Calibration Mode Instructions

**When to calibrate:**
- First time using the pump
- Pump performance changes (low battery, different tubing, etc.)
- Flow rate seems inaccurate

---

## Step-by-Step

### 1. Prepare
Turn potentiometer to **MIN (0)** — this prevents accidental pump start.

### 2. Enter Calibration Mode
Press and **HOLD reset button for 3+ seconds**.
- After 3 seconds, LCD shows `CALIBRATING...`
- Release the button.

### 3. Pump Runs Automatically
Wait **5 seconds**.
- Pump runs at full speed automatically
- LCD shows countdown: `Time: 1s`, `Time: 2s`, etc.

### 4. Collect Output
Collect the pump output in a **measuring container**.

### 5. Input Your Measurement
After 5 seconds:
- Pump stops
- LCD shows `ENTER ML: 0.0`
- LCD shows `RATE: ---`

**Read your measuring container** — if you collected 4.2ml:
- Turn potentiometer until LCD shows `ENTER ML: 4.2`
- The RATE line updates automatically (e.g., `RATE: 0.840 ml/s`)

### 6. Save
Press reset button **briefly (short press)**.
- LCD shows `CALIB SAVED!`
- New flow rate saved to EEPROM memory

---

## Cancel Calibration

Press and **HOLD reset button for 3+ seconds** → LCD shows `CALIB CANCELLED`

---

## Verify

On next startup, LCD briefly shows your saved rate:
```
LCD OK Rate: 0.840
```

---

## How It Works

| Step | What Happens |
|---|---|
| Calibration runs | 5 seconds at full speed (PWM 255) |
| You measure | Actual volume collected |
| You input | Potentiometer sets measured volume (0.0 - 5.0 ml) |
| Save | Calculates `flowRate = volume / 5 seconds` |
| Auto-stop uses | `flowRate` for volume estimate |

**Example:** If 4.2ml collected in 5 seconds → `flowRate = 0.84 ml/s`
- Next time auto-stop triggers at 5ml, it runs for ~6 seconds

---

## Tips

- **Maximum input is 5.0ml** (matches TARGET_VOLUME)
- If you got more than 5ml, something is wrong with pump/tubing
- If you got less than 1ml, check for clogs
- Recalibrate if pump performance changes

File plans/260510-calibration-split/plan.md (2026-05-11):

---
title: "Split Calibration & Prioritize Pot Time"
description: "Move calibration to calibration.h and ensure pot time always overrides calibration"
status: pending
priority: P1
effort: 2h
branch: main
tags: [calibration, arduino, refactor]
created: 2026-05-10
---

# Plan: Calibration Split + Pot Priority

## Context
User wants:
1. Move all calibration code to separate `calibration.h` file
2. Ensure manual potentiometer (A2) time always takes priority over any calibrated flow rate values

## Problem Analysis
Current issue: Pump duration seems controlled by calibrated flowRateCalibrated (auto-stop at 5ml) rather than pot-set time. User wants pot time to be the primary control.

## Phases

### Phase 1: Extract Calibration to Header
- Create `calibration.h` with all calibration logic
- Remove calibration code from main `.ino`
- Add `#include "calibration.h"`

### Phase 2: Fix Pot Time Priority
- Ensure `capturedProcessTime` from pot always controls pump duration
- Auto-stop at 5ml should be secondary (only if pot time allows)
- Add debug output to verify pot reading

### Phase 3: Verify
- Compile and test pump duration follows pot setting

## Related Files
- `ArtemiaCode/ArtemiaCode.ino` - main sketch
- `ArtemiaCode/calibration.h` - NEW

## Dependencies
None - standalone refactoring task

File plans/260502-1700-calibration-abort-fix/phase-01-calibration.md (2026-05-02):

---
title: "Phase 1: Calibration Mode with EEPROM"
description: "Implement pump calibration mode with persistent FLOW_RATE storage"
status: pending
owner: claude
priority: P2
created: 2026-05-02
---

## Context Links

- Parent: [plan.md](../plan.md)
- Deps: [phase-02-abort-fix.md](./phase-02-abort-fix.md)
- Code: `ArtemiaCode/ArtemiaCode.ino`

## Overview

Add calibration mode that lets user measure actual flow rate and save to EEPROM.

### Calibration Flow

1. In IDLE, long-press reset button (>3s) to enter calibration
2. Pump runs for 5 seconds at full speed
3. After 5s, display prompts user to enter measured volume via potentiometer
4. Short-press saves new FLOW_RATE to EEPROM, long-press cancels

## Implementation Steps

### 1. Add EEPROM and State Variables

```cpp
#include <EEPROM.h>

enum SystemState { IDLE, PUMPING, CALIBRATING, CALIB_INPUT };
SystemState systemState = IDLE;

const int CALIB_DURATION = 5000;  // 5 seconds
const int CALIB_LONG_PRESS = 3000; // 3 seconds to enter calib
const int CALIB_SAVE_ADDR = 0;
const float EEPROM_DEFAULT_RATE = 0.5;

unsigned long calibStartTime = 0;
float calibInputVolume = 0.0;
float flowRateCalibrated = 0.5;
```

### 2. Load FLOW_RATE from EEPROM at startup

```cpp
void loadFlowRate() {
  if (EEPROM.read(CALIB_SAVE_ADDR) == 'A') {
    EEPROM.get(CALIB_SAVE_ADDR + 1, flowRateCalibrated);
  } else {
    flowRateCalibrated = EEPROM_DEFAULT_RATE;
  }
}
```

### 3. Save FLOW_RATE to EEPROM

```cpp
void saveFlowRate() {
  EEPROM.write(CALIB_SAVE_ADDR, 'A');
  EEPROM.put(CALIB_SAVE_ADDR + 1, flowRateCalibrated);
}
```

### 4. Add long-press detection for entering calibration

In `loop()` during IDLE, check long-press:

```cpp
// In IDLE loop:
if (digitalRead(resetBtnPin) == LOW) {
  unsigned long pressStart = millis();
  while (digitalRead(resetBtnPin) == LOW) {
    if (millis() - pressStart > CALIB_LONG_PRESS) {
      // Enter calibration
      systemState = CALIBRATING;
      calibStartTime = millis();
      digitalWrite(pumpDir, HIGH);
      analogWrite(pumpPWM, 255);  // Full speed
      return;
    }
  }
}
```

### 5. Handle CALIBRATING state

```cpp
if (systemState == CALIBRATING) {
  displayUpdate(); // Show calibrating status
  if (millis() - calibStartTime >= CALIB_DURATION) {
    analogWrite(pumpPWM, 0);
    systemState = CALIB_INPUT;
  }
  return; // Skip pump loop
}
```

### 6. Handle CALIB_INPUT state

```cpp
if (systemState == CALIB_INPUT) {
  // Read potentiometer for volume input
  calibInputVolume = map(analogRead(speedPot), 0, 1023, 0, 500) / 100.0; // 0.00 to 5.00 ml

  lcd.setCursor(0, 0);
  lcd.print("ENTER ML:");
  lcd.print(calibInputVolume);

  lcd.setCursor(0, 1);
  lcd.print("RATE:");
  float newRate = calibInputVolume / (CALIB_DURATION / 1000.0);
  lcd.print(newRate);

  lcd.setCursor(0, 3);
  lcd.print("BTN=SAVE LONG=CANCEL");
  return;
}
```

### 7. Short-press in CALIB_INPUT saves, long-press cancels

```cpp
// After calibration input:
if (digitalRead(resetBtnPin) == LOW) {
  unsigned long pressStart = millis();
  while (digitalRead(resetBtnPin) == LOW) {
    if (millis() - pressStart > CALIB_LONG_PRESS) {
      systemState = IDLE;
      lcd.setCursor(0, 2);
      lcd.print("CALIB CANCELLED   ");
      return;
    }
  }
  // Short press - save
  flowRateCalibrated = calibInputVolume / (CALIB_DURATION / 1000.0);
  saveFlowRate();
  systemState = IDLE;
}
```

### 8. Use flowRateCalibrated instead of FLOW_RATE constant

Replace `FLOW_RATE` usage with `flowRateCalibrated` in volume calculations.

## Todo List

- [ ] Add EEPROM library and state variables
- [ ] Implement loadFlowRate() on startup
- [ ] Implement saveFlowRate() function
- [ ] Add long-press detection to enter calibration
- [ ] Handle CALIBRATING state (5s pump run)
- [ ] Handle CALIB_INPUT state (potentiometer volume input)
- [ ] Implement short-press save, long-press cancel
- [ ] Replace FLOW_RATE with flowRateCalibrated

## Success Criteria

- Long-press 3s enters calibration mode
- Pump runs exactly 5 seconds during calibration
- Potentiometer allows setting 0-5ml measured volume
- Short-press saves new FLOW_RATE to EEPROM
- Long-press cancels without saving
- FLOW_RATE persists across reboots
- Existing pump/lcd code unchanged (except uses new flow rate)

## Risk Assessment

- EEPROM wear: minimal (only on user-initiated calibration)
- Accuracy: depends on user measurement precision
- Debounce: long- press detection needs stable reading

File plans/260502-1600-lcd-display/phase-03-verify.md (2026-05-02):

---
title: "Verify Compilation Phase"
description: "Verify Arduino code compiles without errors after LCD changes"
status: completed
priority: P2
effort: 30m
branch: main
tags: [arduino, lcd]
created: 2026-05-02
---

# Phase 03: Verify Compilation

## Context Links

- Phase 01: `./phase-01-lcd-init.md`
- Phase 02: `./phase-02-lcd-display.md`

## Overview

- Priority: P2
- Status: Pending
- Compile and verify the modified Arduino code

## Key Insights

- User must have Arduino IDE or CLI with LiquidCrystal_I2C library installed
- Board target: Arduino Uno (based on code structure)

## Requirements

- Arduino IDE or arduino-cli
- LiquidCrystal_I2C library installed via Library Manager
- Board: Arduino Uno/Nano

## Success Criteria

- Code compiles without errors
- No "library not found" warnings
- No "undefined reference" errors

## Risk Assessment

- Missing library: user needs to install via Library Manager
- Board mismatch: verify target board matches code

## Notes

- Full path: `D:\AShiroru\ProgramCode\Project\Team\ArtemiaFillingMachines\ArtemiaCode\ArtemiaCode.ino`

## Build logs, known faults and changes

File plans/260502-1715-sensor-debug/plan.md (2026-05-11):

---
title: "Photoelectric Sensor PNP Fix"
description: "Fix sensor logic for PNP type sensor - detect HIGH instead of LOW"
status: completed
priority: P1
effort: 15m
branch: main
tags: [arduino, debug, photoelectric-sensor, bugfix]
created: 2026-05-02
---

# Photoelectric Sensor PNP Fix Plan

## Root Cause CONFIRMED

**Sensor is PNP type.** PNP sensors output HIGH when object detected (opposite of NPN).

| Sensor Type | Output When Object DETECTED | Code Check |
|---|---|---|
| NPN (open-collector) | LOW | `digitalRead() == LOW` |
| **PNP (active-high)** | **HIGH** | `digitalRead() == HIGH` |

**Current code is wrong:**
```cpp
if (digitalRead(sensorPin) == LOW &&  // ← Wrong for PNP!
```

This causes random noise LOW signals to trigger count++, making it auto-count.

## Fix (Single Change)

### In ArtemiaCode.ino, change line ~78:

**FROM:**
```cpp
  if (digitalRead(sensorPin) == LOW &&
      millis() - lastSensorTrigger > DEBOUNCE_SENSOR) {
```

**TO:**
```cpp
  if (digitalRead(sensorPin) == HIGH &&
      millis() - lastSensorTrigger > DEBOUNCE_SENSOR) {
```

### Also change pinMode from INPUT_PULLUP to INPUT:

**FROM:**
```cpp
  pinMode(sensorPin, INPUT_PULLUP);
```

**TO:**
```cpp
  pinMode(sensorPin, INPUT);
```

**Reason:** PNP outputs HIGH when detected, so no pullup needed. The sensor's own output drives the line. A 10kΩ pull-down resistor between signal and GND is recommended to prevent floating when sensor is OFF.

## Hardware Addition (Optional)

Add 10kΩ pull-down resistor:
```
Signal (sensor) ─────┬──── Arduino pin D10
                     │
                   10kΩ
                     │
                    GND
```

This prevents floating noise when sensor output is HIGH-to-HIGHZ (transition state).

## Todo List

- [ ] Change `digitalRead(sensorPin) == LOW` to `HIGH`
- [ ] Change `pinMode(sensorPin, INPUT_PULLUP)` to `INPUT`
- [ ] (Optional) Add 10kΩ pull-down resistor

## Success Criteria

- Sensor shows HIGH when object detected
- tubeCount increments only when object passes
- No auto-counting when nothing is in front of sensor
- Existing pump/lcd code unchanged

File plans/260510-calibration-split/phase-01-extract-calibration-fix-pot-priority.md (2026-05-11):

# Phase 1: Extract Calibration to Header + Fix Pot Priority

## Context
- Parent plan: `plans/260510-calibration-split/plan.md`
- Related docs: `docs/operation-rules.md`

## Overview
- Date: 2026-05-10
- Priority: P1
- Status: pending
- Description: Move calibration logic to calibration.h, ensure pot time takes priority over calibration for pump duration

## Key Insights

### Issue 1: Pump timeout not following pot
Current code has TWO stop conditions for pump:
1. **Time-based** (capturedProcessTime from pot A2): `millis() - stateStartTime >= capturedProcessTime * 1000`
2. **Volume-based** (flowRateCalibrated): `currentVolume >= TARGET_VOLUME` (5ml)

**Problem**: If flowRateCalibrated is high, volume check triggers first (~5s), ignoring pot time.

**Fix**: Make pot time the primary controller. Volume auto-stop should only trigger if pot time is > actual fill time needed.

### Issue 2: Calibration code mixed in main sketch
Calibration functions and variables scattered in main .ino make it hard to maintain.

## Requirements
1. Extract calibration to `calibration.h`
2. Pot time (A2) must always control pump duration
3. Volume auto-stop (5ml) is secondary - only stops early if volume reached before pot time expires
4. Debug output to LCD to verify pot reading

## Architecture

### New File: `calibration.h`
```cpp
#ifndef CALIBRATION_H
#define CALIBRATION_H

// Calibration constants
#define CALIB_DURATION 5000       // 5 seconds
#define CALIB_LONG_PRESS 3000     // 3 seconds to enter calib
#define CALIB_SAVE_ADDR 0
#define EEPROM_MAGIC 'A'
#define EEPROM_DEFAULT_RATE 0.5

// Global calibration variables (declared extern for .ino access)
extern unsigned long calibStartTime;
extern float calibInputVolume;
extern float flowRateCalibrated;
extern bool calibBtnWasHigh;
extern unsigned long calibPressStart;

// Functions
void loadFlowRate();
void saveFlowRate();
void handleCalibrationState(LiquidCrystal_I2C &lcd, int speedPotPin, int resetBtnPin);

#endif
```

### Modified: `PUMP_FILL` logic
```cpp
// Check timeout FIRST (pot time is primary)
if (millis() - stateStartTime >= (unsigned long)capturedProcessTime * 1000UL) {
  // Timeout - stop pump
  // ...stop pump, count tube...
}
// Only check volume auto-stop AFTER confirming pot time hasn't expired
else {
  float currentVolume = (millis() - pumpStartTime) / 1000.0 * flowRateCalibrated;
  if (currentVolume >= TARGET_VOLUME) {
    // Volume reached before timeout - stop pump
    // ...stop pump, count tube...
  }
}
```

## Related Code Files
- `ArtemiaCode/ArtemiaCode.ino` - modify (remove calibration, fix PUMP_FILL)
- `ArtemiaCode/calibration.h` - create (all calibration logic)

## Implementation Steps

### Step 1: Create `calibration.h`
Create header with:
- Calibration constants
- Extern variable declarations
- Function prototypes

### Step 2: Move calibration functions from .ino to .h
Move to inside calibration.h (or create calibration.cpp):
- `loadFlowRate()`
- `saveFlowRate()`
- Calibration button handling (loop section lines 251-271)
- `handleStateMachine()` for calibration

### Step 3: Modify `ArtemiaCode.ino`
- Add `#include "calibration.h"` at top
- Remove lines 31-41 (calibration constants/variables)
- Remove lines 88-99 (loadFlowRate, saveFlowRate)
- Remove lines 251-271 (calibration button handling)
- Remove handleStateMachine() function (lines 471-583)
- Add `pinMode(timePot, INPUT);` in setup if missing

### Step 4: Fix PUMP_FILL logic
Ensure timeout check happens BEFORE volume check. Pot time must always be primary.

## Todo List
- [ ] Create calibration.h with all calibration code
- [ ] Modify ArtemiaCode.ino to remove calibration code
- [ ] Add include for calibration.h
- [ ] Fix PUMP_FILL to prioritize pot time over volume auto-stop
- [ ] Add debug LCD output for pot value reading

## Success Criteria
1. Calibration mode still works (long-press 3s to enter)
2. Pump duration follows pot setting (2-20s) not calibration
3. Volume auto-stop (5ml) only triggers if pot time allows
4. LCD shows correct pot reading

## Risk Assessment
- **Risk**: Breaking calibration functionality during move
- **Mitigation**: Keep backup of current .ino, test calibration mode after changes

## Security Considerations
None - offline Arduino project

## Next Steps
Test pump duration with pot set to max (20s) - should run full 20s not 5-7s

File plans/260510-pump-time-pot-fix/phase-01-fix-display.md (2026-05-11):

# Fix: Pump Time Potentiometer Display Bug

## Bug Summary
LCD display shows wrong time value because `displayUpdate()` reads pot directly instead of using `readPotTime()`, causing inconsistency between displayed time and actual pump timeout.

## Root Cause
- `displayUpdate()` (line 610-611) manually maps pot value: `map(potValue, 0, 1023, 2, 20)`
- `readPotTime()` (line 224-227) does same mapping but via function call
- Both should give same result, BUT `displayUpdate()` lacks proper LCD field clearing

## Fix Required
```cpp
// Line 3: "Time:Xs" - Change FROM:
int potValue = analogRead(timePot);
int processingTime = map(potValue, 0, 1023, 2, 20);
lcd.setCursor(0, 3);
lcd.print("Time:");
lcd.print(processingTime);
lcd.print("s            ");

// TO:
lcd.setCursor(0, 3);
lcd.print("Time:");
lcd.print(readPotTime());
lcd.print("s      ");  // 6 spaces to clear old value if previously "20s"
```

## Files to Modify
- `ArtemiaCode.ino`: Lines 609-615

## Validation
1. Turn pot to minimum (2s) → LCD shows "Time:2s"
2. Turn pot to maximum (20s) → LCD shows "Time:20s"
3. Verify pump timeout matches displayed time

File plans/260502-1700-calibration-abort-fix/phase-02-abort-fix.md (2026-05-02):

---
title: "Phase 2: Abort Button Stop/Reset Fix"
description: "Fix abort button to stop pump immediately and reset state when pressed during pumping"
status: pending
owner: claude
priority: P2
created: 2026-05-02
---

## Context Links

- Parent: [plan.md](../plan.md)
- Deps: [phase-01-calibration.md](./phase-01-calibration.md)
- Code: `ArtemiaCode/ArtemiaCode.ino`

## Overview

Fix abort button to stop pump immediately and reset all counters when pressed during pumping or idle.

### Current Problem

- Reset button only resets `tubeCount`
- Doesn't stop pump if running
- Doesn't reset pump volume/runtime

### Fix Behavior

| State | Abort Button Action |
|---|---|
| PUMPING | Stop pump, reset pumpRuntime/pumpVolume/tubeCount to 0 |
| IDLE | Reset tubeCount to 0 (existing behavior) |
| CALIBRATING | Cancel calibration, return to IDLE |
| CALIB_INPUT | Cancel calibration, return to IDLE |

## Implementation Steps

### 1. Add abortCheck() function for centralized handling

```cpp
void abortAll() {
  // Stop pump if running
  analogWrite(pumpPWM, 0);
  digitalWrite(pumpDir, LOW);

  // Reset pump state
  pumpRuntime = 0;
  pumpVolume = 0.0;
  pumpRunning = false;
  currentSpeed = 0;

  // Reset tube count
  tubeCount = 0;

  // Exit any special mode
  systemState = IDLE;

  // Show abort message
  lcd.clear();
  lcd.setCursor(0, 1);
  lcd.print("!! ABORTED !!");
  delay(1000);
  displayUpdate();
}
```

### 2. Replace direct button check with abortCheck()

Current code:
```cpp
if (digitalRead(resetBtnPin) == LOW) {
  tubeCount = 0;
  delay(DEBOUNCE_BUTTON);
}
```

New code:
```cpp
if (digitalRead(resetBtnPin) == LOW) {
  delay(DEBOUNCE_BUTTON);  // Debounce first
  if (digitalRead(resetBtnPin) == LOW) {  // Still pressed = real press
    abortAll();
    // Skip rest of loop to avoid re-triggering
    return;
  }
}
```

### 3. Integration with pump running block

In the pump running block, check abort button continuously:

```cpp
// Inside pump running block (delay loop):
int pumpSpeed = readPotSpeed();
currentSpeed = pumpSpeed;
pumpRunning = true;
pumpStartTime = millis();
digitalWrite(pumpDir, HIGH);
analogWrite(pumpPWM, pumpSpeed);
displayUpdate();

unsigned long pumpLoopStart = millis();
while (pumpRunning) {
  // Check abort every iteration
  if (digitalRead(resetBtnPin) == LOW) {
    abortAll();
    return;
  }

  // Check volume auto-stop
  float currentVolume = (millis() - pumpStartTime) / 1000.0 * flowRateCalibrated;
  if (currentVolume >= TARGET_VOLUME) {
    analogWrite(pumpPWM, 0);
    pumpRuntime += millis() - pumpStartTime;
    pumpVolume = pumpRuntime / 1000.0 * flowRateCalibrated;
    pumpRunning = false;
    currentSpeed = 0;
    displayUpdate();
    return;
  }

  // Check if delay elapsed
  if (millis() - pumpLoopStart >= 2000) {
    analogWrite(pumpPWM, 0);
    pumpRuntime += millis() - pumpStartTime;
    pumpVolume = pumpRuntime / 1000.0 * flowRateCalibrated;
    pumpRunning = false;
    currentSpeed = 0;
    displayUpdate();
    return;
  }

  displayUpdate();
}
```

## Todo List

- [ ] Add abortAll() function
- [ ] Add abort check in pump running loop
- [ ] Add abort check in loop() main section
- [ ] Verify abort works in all states

## Success Criteria

- Pressing abort button while pumping stops pump immediately
- All counters (pumpRuntime, pumpVolume, tubeCount) reset to 0
- "ABORTED" message shows briefly on LCD
- Pressing abort in IDLE still just resets tubeCount
- No double-triggering from button bounce

## Risk Assessment

- Button bounce: debounce delay before checking second time
- State leakage: ensure all states cleared on abort
- Return in loop: prevents further processing after abort

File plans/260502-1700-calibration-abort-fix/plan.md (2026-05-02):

---
title: "Pump Calibration + Abort Button Fix"
description: "Add flow rate calibration mode and fix abort button to stop/reset pump"
status: pending
priority: P2
effort: 1h
branch: main
tags: [arduino, calibration, pump-control, bugfix]
created: 2026-05-02
---

# Pump Calibration + Abort Button Fix Plan

## Overview

Two fixes/improvements:
1. **Calibration mode**: Let user run pump for fixed time, input actual volume to auto-calculate FLOW_RATE
2. **Abort button fix**: When pressed, immediately stop pump and reset tube counter

## Requirements

### 1. Calibration Mode

- Enter calibration via long-press (>3s) on reset button during IDLE state
- During calibration:
  - Pump runs for 5 seconds at full speed
  - Display shows "CALIBRATING..."
  - After 5s, pump stops, display shows "ENTER ML:"
- User turns potentiometer to set measured volume (shown on LCD)
- Short-press to save and exit, long-press to cancel
- New FLOW_RATE saved to EEPROM so it persists across reboots

### 2. Abort Button Fix

- Current problem: reset button only resets `tubeCount`, not pump
- Fix: when Abort button pressed while pump running:
  - Stop pump immediately (analogWrite 0)
  - Reset `pumpRuntime`, `pumpVolume` to 0
  - Reset `tubeCount` to 0
  - Show "ABORTED" briefly on LCD
- When Abort pressed while IDLE: just reset tubeCount (existing behavior)

## Architecture

### State Machine

```
IDLE → (long-press 3s) → CALIBRATING → (5s elapsed) → CALIB_INPUT → (short-press) → IDLE
                   ↘ (long-press) ↗                              ↗ (long-press) ↗

IDLE → (pump running) → PUMPING → (done OR volume>=5ml OR abort) → IDLE
                  (abort button) → STOP_ABORT → IDLE
```

### New Variables

```cpp
// Calibration
float flowRateCalibrated = 0.5;  // loaded from EEPROM
const int CALIB_DURATION = 5000; // ms
const int CALIB_LONG_PRESS = 3000; // ms
bool calibMode = false;
unsigned long calibStartTime = 0;

// State enum
enum SystemState { IDLE, PUMPING, CALIBRATING, CALIB_INPUT };
SystemState systemState = IDLE;
```

### EEPROM Layout

| Address | Description |
|---|---|
| 0 | 'A' magic byte (valid flag) |
| 1-4 | FLOW_RATE float |

## Display Format

### Calibration States

| State | Row 0 | Row 1 | Row 2 | Row 3 |
|---|---|---|---|---|
| IDLE | Speed: XXX | Motor: XXXX | PumpVol: X.XX ml | Tubes: XX |
| CALIBRATING | CALIBRATING... | Time: Xs | Vol: X.XX ml | |
| CALIB_INPUT | ENTER ML: X.X | FLOW_RATE: X.XX | <-POT-> | SAVE=BTN |
| ABORTED | !! ABORTED !! | PumpVol: 0.00 ml | Tubes: 0 | (auto-return) |

## Phases

| # | Phase | Status | Effort | Link |
|---|---|---|---|---|
| 1 | Calibration mode with EEPROM | pending | 30m | [phase-01](./phase-01-calibration.md) |
| 2 | Abort button stop/reset fix | pending | 30m | [phase-02](./phase-02-abort-fix.md) |

## Dependencies

- Existing: LCD 16x4 I2C, pump L298N, potentiometer, photoelectric sensor, reset button
- EEPROM library: `<EEPROM.h>` (Arduino built-in)
- No new hardware needed

## Risk Assessment

- EEPROM write wear: only write during calibration (user-initiated), negligible
- Calibration accuracy: depends on user measurement precision
- State machine complexity: keep simple, only 4 states

## Unresolved Questions

- None — requirements are clear from user description

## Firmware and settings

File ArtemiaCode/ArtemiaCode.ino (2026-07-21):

// --- ĐỊNH NGHĨA CHÂN CHO TRỤC X ---
const int stepPin = 2;    // Chân phát xung cho trục X
const int dirPin = 5;     // Chân điều khiển hướng cho trục X

// --- LCD 16x4 I2C (PCF8574) ---
#include <Wire.h>
#include <LiquidCrystal_I2C.h>
#include <EEPROM.h>
LiquidCrystal_I2C lcd(0x27, 16, 4);

// --- STATE MACHINE ---
enum SystemState { IDLE, PUMPING };
SystemState systemState = IDLE;

enum HandleState {
  ROTATING,        // Stepper rotating 1 revolution
  SENSOR_CHECK,    // After rotation, check sensor
  PUMP_WAIT,       // Waiting 3s before pump (tube settled)
  PUMP_FILL,       // Pump running, pot time controls duration
  PUMP_DONE,       // Pump stopped, wait 3s
  NO_TUBE_WAIT     // No tube detected, wait 5s
};
HandleState handleState = ROTATING;
unsigned long stateStartTime = 0;
const int PUMP_WAIT_DELAY = 1000;    // 1s before pump (tube settled)
const int POST_PUMP_DELAY = 3000;    // 3s after pump
const int NO_TUBE_DELAY = 5000;     // 5s when no tube
const unsigned long PUMP_TIMEOUT = 5000; // 5s max pump

// --- PUMP STATE ---
unsigned long pumpStartTime = 0;
bool pumpRunning = false;
float capturedProcessTime = 0;  // Locked time when pumping starts

// --- ĐỊNH NGHĨA CHÂN CHO BƠM NHU ĐỘNG (L298N) ---
const int pumpPWM = 11;   // Chân ENA của L298N nối vào Z+ trên Shield (D11)
const int pumpDir = 13;   // Chân IN1 của L298N nối vào SpnDir trên Shield (D13)
// Lưu ý: Chân IN2 của L298N nối trực tiếp vào GND

// --- CẤU HÌNH THÔNG SỐ MOTOR ---
// Khi chỉ cắm Jumper M0 -> Chế độ 1/2 Step -> 400 bước/vòng
const int stepsPerRev = 100; // 800 step con 200 step là 90 độ

// --- LCD TRACKING VARIABLES ---
unsigned long motorSteps = 0;     // Total step pulses
unsigned long pumpRuntime = 0;    // Pump running time in ms
int currentSpeed = 0;             // Current PWM value
unsigned long lastDisplayUpdate = 0;

// --- POTENTIOMETER ---
const int speedPot = A1;          // Potentiometer for pump speed control
const int timePot = A2;           // Potentiometer for pump process time (2-20s)

// --- PHOTOELECTRIC SENSOR PNP + TUBE COUNTER ---
const int sensorPin = 10;         // Y+ on CNC shield (D10)
const int resetBtnPin = A0;       // Abort signal (A0)

// --- LIMIT SWITCH X+ (CNC SHIELD V3) ---
const int limitSwitch = 9;       // X+ Limit on CNC Shield V3 (D9)

int tubeCount = 0;
unsigned long lastSensorTrigger = 0;
const int DEBOUNCE_SENSOR = 50;
const int DEBOUNCE_BUTTON = 100;
bool lastAbortBtnState = HIGH;   // For edge detection on latch button

void abortAll() {
  // Stop pump if running
  analogWrite(pumpPWM, 0);
  digitalWrite(pumpDir, LOW);

  // Reset pump state
  pumpRuntime = 0;
  pumpRunning = false;
  currentSpeed = 0;

  // Reset tube count
  tubeCount = 0;

  // Exit any special mode
  systemState = IDLE;

  // Reset handle state to start of sequence
  handleState = ROTATING;

  // Show abort message
  lcd.clear();
  lcd.setCursor(0, 1);
  lcd.print("!! ABORTED !!");
  delay(1000);
}

void homeSeekingSequence() {
  const int HOMING_ROTATIONS = 2;
  const int HOMING_STEPS_PER_ROTATION = 400;
  const unsigned long HOMING_PULSE_US = 5500;
  const unsigned long HOMING_PAUSE_US = 1000;

  lcd.clear();
  lcd.setCursor(0, 0);
  lcd.print("HOMING...");

  digitalWrite(dirPin, HIGH);

  for (int rot = 0; rot < HOMING_ROTATIONS; rot++) {
    for (int step = 0; step < HOMING_STEPS_PER_ROTATION; step++) {
      if (digitalRead(limitSwitch) == LOW) {
        lcd.clear();
        lcd.setCursor(0, 0);
        lcd.print("HOMING DONE!");
        delay(2000);
        lcd.clear();
        int x = 10;
        while(x > 0){
          x -= 1;
          lcd.setCursor(0, 0); 
          lcd.print("STARTING... IN "+ String(x));
          delay(1000);
          lcd.clear();     
        }
        
        return;
      }

      digitalWrite(stepPin, HIGH);
      delayMicroseconds(HOMING_PULSE_US);
      digitalWrite(stepPin, LOW);
      delayMicroseconds(HOMING_PAUSE_US);
    }
  }

  lcd.clear();
  lcd.setCursor(0, 0);
  lcd.print("PLEASE TURN OFF");
  lcd.setCursor(9, 1);
  lcd.print("SYSTEM !!!");
  while (1) {
    delay(1000);
  }
}

void setup() {
  // Cấu hình chân cho Stepper
  pinMode(stepPin, OUTPUT);
  pinMode(dirPin, OUTPUT);

  // Không cần pinMode chân 8 hay digitalWrite chân 8 vì đã cắm jumper EN/GND cứng trên mạch
  // pinMode(8, OUTPUT);
  // digitalWrite(8, LOW);

  // Cấu hình chân cho Bơm (L298N)
  pinMode(pumpPWM, OUTPUT);
  pinMode(pumpDir, OUTPUT);
  digitalWrite(pumpDir, LOW);
  analogWrite(pumpPWM, 0);

  // LCD Init
  lcd.init();
  lcd.backlight();
  lcd.setCursor(0, 0);
  lcd.print("LCD OK");
  delay(1500);



  // Potentiometer
  pinMode(speedPot, INPUT);

  // Photoelectric sensor + reset button + limit switch
  pinMode(sensorPin, INPUT);
  pinMode(resetBtnPin, INPUT_PULLUP);
  pinMode(limitSwitch, INPUT_PULLUP);

  // Homing sequence
  homeSeekingSequence();
}

int readPotSpeed() {
  int potValue = analogRead(speedPot);
  return map(potValue, 0, 1023, 0, 255);
}

float readPotTime() {
  int potValue = analogRead(timePot);
  return map(potValue, 0, 1023, 7, 200) / 10.0;  // 2.0s to 20.0s (decimal)
}

void loop() {
  // --- Check reset button (external pull-up circuit) ---
  bool btnState = digitalRead(resetBtnPin);
  if (btnState == LOW && lastAbortBtnState == HIGH) {
    delay(DEBOUNCE_BUTTON);
    if (digitalRead(resetBtnPin) == LOW) {
      abortAll();
      return;
    }
  }
  if (btnState == HIGH && lastAbortBtnState == LOW) {
    lastAbortBtnState = HIGH;
  }

  // --- IDLE: Sensor-driven handle sequence ---
  if (systemState == IDLE) {
    switch (handleState) {
      case ROTATING: {
        // Run stepper 1 revolution
        currentSpeed = 255;
        digitalWrite(dirPin, HIGH);
        for (int x = 0; x < stepsPerRev; x++) {
          digitalWrite(stepPin, HIGH);
          delayMicroseconds(3000);
          digitalWrite(stepPin, LOW);
          delayMicroseconds(100);
          motorSteps++;
        }
        currentSpeed = 0;
        handleState = SENSOR_CHECK;
        stateStartTime = millis();
        break;
      }

      case SENSOR_CHECK: {
        // Check sensor immediately after rotation
        if (digitalRead(sensorPin) == HIGH) {
          // Tube detected - wait 3s then pump
          handleState = PUMP_WAIT;
        } else {
          // No tube - wait 10s
          handleState = NO_TUBE_WAIT;
        }
        stateStartTime = millis();
        break;
      }

      case PUMP_WAIT: {
        // If tube disappears, wait 1s to confirm (debounce tube drop)
        // If tube never returns within 9s total, abort
        unsigned long waitElapsed = millis() - stateStartTime;
        // lcd.setCursor(0, 1);
        // lcd.print("PUMP_WAIT:");
        // lcd.print(waitElapsed / 1000);
        // lcd.print("s     ");
        if (digitalRead(sensorPin) == LOW) {
          // Tube gone - wait 1s before aborting
          if (waitElapsed >= PUMP_WAIT_DELAY + 1000) {
            handleState = ROTATING;
            stateStartTime = millis();
          }
        } else if (waitElapsed >= PUMP_WAIT_DELAY) {
          // Got stable tube for 1s - start pumping
          lcd.setCursor(0, 1);
          lcd.print("START PUMP!    ");
          handleState = PUMP_FILL;
          stateStartTime = millis();
          // Capture time from potentiometer (locked for this cycle)
          capturedProcessTime = readPotTime();
          // Start pump
          int pumpSpeed = readPotSpeed();
          currentSpeed = pumpSpeed;
          pumpRunning = true;
          pumpStartTime = millis();
          digitalWrite(pumpDir, HIGH);
          analogWrite(pumpPWM, pumpSpeed);
        } else if (waitElapsed >= 9000) {
          // Tube not stable within 9s - abort and rotate
          handleState = ROTATING;
          stateStartTime = millis();
        }
        break;
      }

      case PUMP_FILL: {
        // SAFETY: If tube disappears during pumping, stop pump immediately
        unsigned long elapsed = millis() - stateStartTime;
        if (digitalRead(sensorPin) == LOW) {
          analogWrite(pumpPWM, 0);
          digitalWrite(pumpDir, LOW);
          pumpRuntime += millis() - pumpStartTime;
          pumpRunning = false;
          currentSpeed = 0;
          // Do NOT count - tube disappeared mid-process
          lcd.clear();
          lcd.setCursor(0, 1);
          lcd.print("TUBE LOST! SKIP ");
          delay(1500);
          handleState = ROTATING;
          stateStartTime = millis();
          lcd.clear();
          break;
        }
        // Check timeout ONLY - pot time controls pump duration
        if (millis() - stateStartTime >= (unsigned long)(capturedProcessTime * 1000.0)) {
          // Timeout - stop pump
          analogWrite(pumpPWM, 0);
          digitalWrite(pumpDir, LOW);
          pumpRuntime += (unsigned long)(capturedProcessTime * 1000.0);
          pumpRunning = false;
          currentSpeed = 0;
          tubeCount++;
          handleState = PUMP_DONE;
          stateStartTime = millis();
        }
        break;
      }

      case PUMP_DONE: {
        if (millis() - stateStartTime >= POST_PUMP_DELAY) {
          handleState = ROTATING;
        }
        break;
      }

      case NO_TUBE_WAIT: {
        // Poll sensor during wait - if tube placed, go to pump immediately
        if (digitalRead(sensorPin) == HIGH) {
          handleState = PUMP_WAIT;
          stateStartTime = millis();
        } else if (millis() - stateStartTime >= NO_TUBE_DELAY) {
          handleState = ROTATING;
        }
        break;
      }
    }

    displayUpdate();
  }
}

void runPumpCycle() {
  int pumpSpeed = readPotSpeed();
  float processTime = readPotTime();
  currentSpeed = pumpSpeed;
  pumpRunning = true;
  pumpStartTime = millis();
  unsigned long pumpDuration = (unsigned long)(processTime * 1000.0);
  digitalWrite(pumpDir, HIGH);
  analogWrite(pumpPWM, pumpSpeed);
  displayUpdate();

  while (millis() - pumpStartTime < pumpDuration && pumpRunning) {
    // Check abort
    bool btnState = digitalRead(resetBtnPin);
    if (btnState == LOW && lastAbortBtnState == HIGH) {
      delay(DEBOUNCE_BUTTON);
      if (digitalRead(resetBtnPin) == LOW) {
        analogWrite(pumpPWM, 0);
        digitalWrite(pumpDir, LOW);
        pumpRuntime = 0;
        pumpRunning = false;
        currentSpeed = 0;
        systemState = IDLE;
        lcd.clear();
        lcd.setCursor(0, 1);
        lcd.print("!! ABORTED !!");
        delay(1000);
        lastAbortBtnState = LOW;
        return;
      }
    }
    if (btnState == HIGH && lastAbortBtnState == LOW) {
      lastAbortBtnState = HIGH;
    }
    delay(50);
  }

  // Normal stop after pot time
  analogWrite(pumpPWM, 0);
  digitalWrite(pumpDir, LOW);
  pumpRuntime += (unsigned long)(processTime * 1000.0);
  pumpRunning = false;
  currentSpeed = 0;
  displayUpdate();
}

void displayUpdate() {
  // Line 0: "MAY CHIET ARTERMIA"
  lcd.setCursor(0, 0);
  lcd.print("MAY CHIET ARTERMIA");

  // Line 1: "Speed:XXX" - show configured speed from pot
  lcd.setCursor(0, 1);
  lcd.print("Speed:");
  lcd.print(readPotSpeed());
  lcd.print("    ");

  // Line 2: "Tubes:X |....|"
  lcd.setCursor(0, 2);
  lcd.print("Tubes:");
  lcd.print(tubeCount);
  lcd.print("    ");
  if (digitalRead(sensorPin) == HIGH) {
    lcd.print("||||||");
  } else {
    lcd.print("------");
  }

  // Line 3: "Time:X.Xs"
  float potTime = readPotTime();
  lcd.setCursor(0, 3);
  lcd.print("Time:");
  lcd.print(potTime, 1);  // 1 decimal place
  lcd.print("s        ");
}

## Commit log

2026-04-25 feat: add gitignore and update arduino code
    Add .gitignore excluding .claude directory and update ArtemiaCode
    with latest changes.
    [main.fzz]
2026-04-30 feat: connection photoeletric sensor and potentition.
    [main.fzz]
2026-05-02 feat: add LCD 16x4 I2C display showing pump speed, motor rotation count, and volume
2026-05-02 feat: fix LCD speed display and add potentiometer for pump speed control
    [ArtemiaCode.ino]
2026-05-02 feat: add photoelectric sensor tube counter, 5ml auto-stop pump, and LCD row 3
    - Photoelectric sensor on D10 (PNP: HIGH=detected), tube counting with debounce
    - Reset button on A0 to clear tube count
    - Auto-stop pump when volume >= 5ml
    - LCD row 3 shows tube count
2026-05-02 docs: add calibration mode documentation and design plan
    Add user documentation for calibration procedure and implementation
    plan with phase breakdown for calibration mode and abort button fix.
2026-05-02 fix: separate calibration button tracking from abort handling
    Use dedicated calibPressStart and calibBtnWasHigh variables instead
    of lastAbortBtnState to avoid state conflict when entering calibration
    mode after abort. Calibration now properly detects long- press release
    regardless of abort button state.
    [ArtemiaCode.ino]
2026-05-02 feat: add lever limit switch component for Fritzing
2026-05-03 feat: add NEMA homing sequence with limit switch on startup
    - Add limit switch X+ (D9) for home detection on CNC Shield V3
    - Implement homeSeekingSequence() with 2-rotation timeout
    - Motor rotates slowly checking switch each step
    - If home found: count down 10s delay before pump activation
    - If home not found: display error and halt system
    [ArtemiaCode.ino]
2026-05-03 feat: implement sensor-driven artemia handling sequence with state machine
    - Replace hardcoded rotation+pump loop with 6-state HandleState machine
    - States: ROTATING → SENSOR_CHECK → PUMP_WAIT (3s) → PUMP_FILL → PUMP_DONE (5s) → NO_TUBE_WAIT (10s, polls sensor)
    - Disable old sensor counting in loop (conflicted with state machine)
    - Rename PUMPING → PUMP_FILL to avoid redeclaration conflict with SystemState
    - LCD now shows MAY CHIET ARTERMIA title with Speed, Tubes, Time, Sensor status
    [ArtemiaCode.ino]
2026-05-03 docs: add time potentiometer A2 and lock-time rule to operation rules
    - Add A2 time potentiometer pin mapping (2-20s range)
    - Document process time lock rule during pumping
    - Add PROCESS_TIME_MIN/MAX constants
    - Update PUMP_TIMEOUT description as fallback
2026-05-03 fix: improve pump timeout and sensor debounce stability
    - Prioritize timeout over volume auto-stop so configured time always runs fully
    - Reset PUMP_WAIT timer when tube disappears instead of aborting immediately
    - Only start pumping after tube stays stable for full 3s
    - Display configured speed from pot instead of current running speed
    - Add readPotTime() function for time potentiometer on A2
    [ArtemiaCode.ino]
2026-05-03 chore: update Fritzing wiring and operation rules
    [main.fzz]
2026-05-03 docs: update operation rules for stable tube detection and timeout priority
2026-05-11 refactor: simplify artemia code and update Fritzing wiring
    - Reduce main loop complexity by extracting state machine logic
    - Improve pump timeout handling and sensor debounce stability
    - Update Fritzing breadboard layout for calibration split feature
    [main.fzz]
2026-07-21 fix: enable reset button monitoring and optimize tube detection timeouts in ArtemiaCode.ino
    [main.fzz]
